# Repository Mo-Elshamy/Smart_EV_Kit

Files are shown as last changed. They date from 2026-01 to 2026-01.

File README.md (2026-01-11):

# Smart EV Kit — Project Overview

The Smart EV Kit combines a Raspberry Pi–based Vehicle Control Unit (VCU) and a set of mechanical parts for an educational electric buggy platform. It integrates secure access (NFC), a touchscreen dashboard, ultrasonic safety sensors, and addressable LED lighting for prototyping and learning.

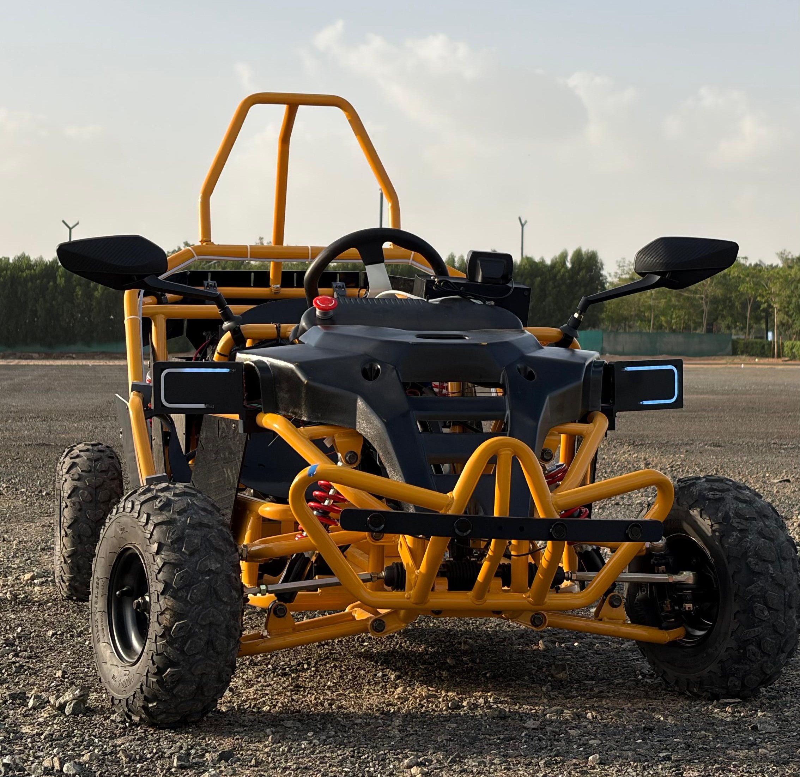
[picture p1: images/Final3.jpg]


---

## [Software & Electrical Hardware](software/Software.md)

Overview: The software stack is written in Python and provides a touch-friendly dashboard, hardware abstraction, and background services for sensors and actuators. Key components include the GUI (`main.py` using PyQt5), the hardware abstraction layer (`hardware.py`) which manages GPIO, SPI (NFC), ultrasonic sensors, LED animations, relays, and the DHT sensor loops.

Electrical hardware summary: Designed for a Raspberry Pi 4 with a 7" HDMI touchscreen, the system uses eight HC-SR04 ultrasonics (echo lines protected by voltage dividers), an RC522 NFC reader on SPI, a WS2811 12V LED strip driven via PWM-capable GPIO, a 2-channel relay module (active-low), and a DHT11 environmental sensor. Power conversion is expected via 48V→12V and 48V→5V buck converters.
Front Bar

---

## [Mechanical](mechanical/Mechacinal.md)

Overview: Mechanical assets include 3D-printed mounts, a multi-part control box, sensor bars, and laser-cut acrylic body panels. The documentation lists fitment issues and recommended V2 improvements (tolerance adjustments, mounting standoffs, and cutout updates) and contains a student steering prototype activity.
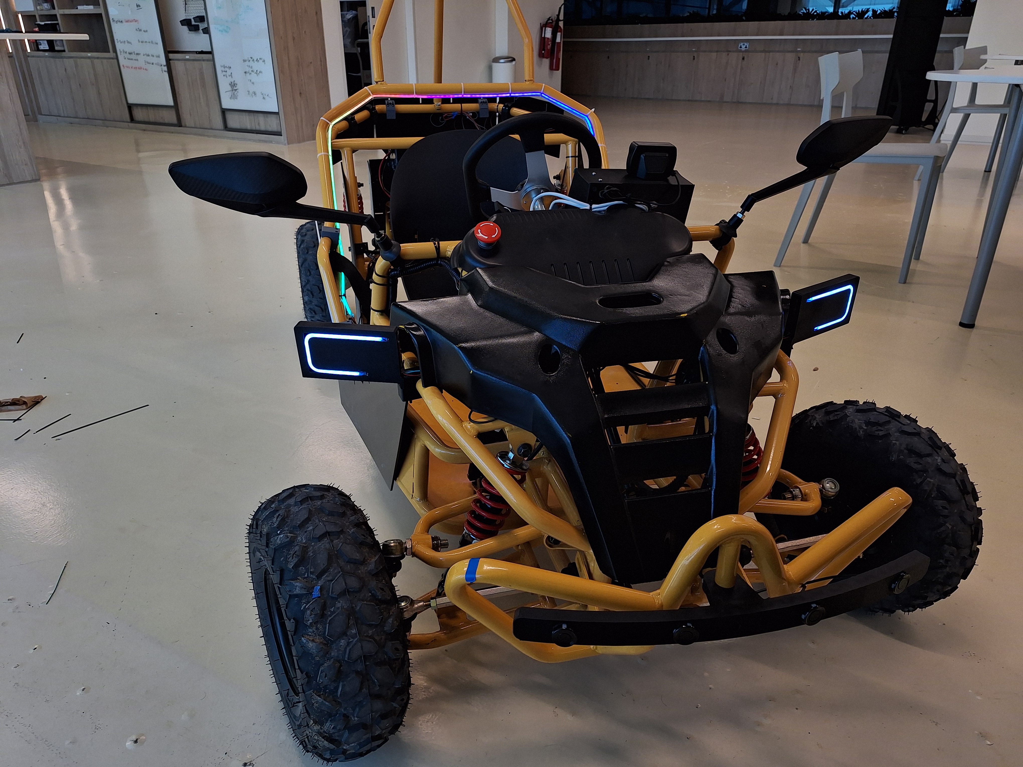
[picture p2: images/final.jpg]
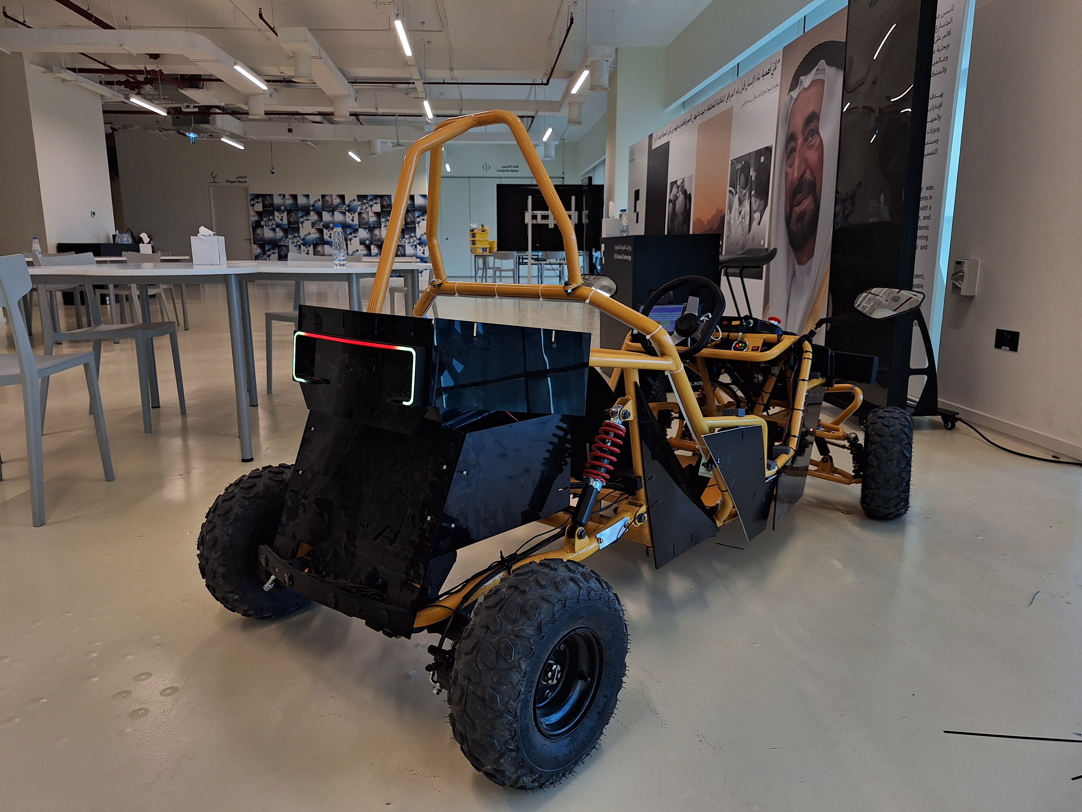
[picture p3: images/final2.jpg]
 |

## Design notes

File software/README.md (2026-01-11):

# RQ EV Car Control System

**Version:** 1.0.0 **Platform:** Raspberry Pi 4 Model B (Bookworm OS)

## 1. Project Overview

The **RQ EV Car Control System** is a centralized Vehicle Control Unit (VCU) designed for electric buggies and educational EV platforms. Built on the Raspberry Pi 4 architecture, it integrates safety sensors, access control, and lighting management into a single, cohesive system.

This project replaces traditional analog car switches with a modern, 7-inch touchscreen interface (`PyQt5`), offering a digital driving experience similar to modern commercial electric vehicles.

### Key Features

* **Keyless Authentication:** Secure NFC/RFID access control prevents the vehicle from starting without an authorized key card.
* **Intelligent Safety System:** An 8-sensor ultrasonic array provides real-time parking assistance with visual radar feedback and variable frequency audio warnings.
* **Dynamic Lighting:** Controls addressable WS2811 LED strips for Headlights, Taillights, Turn Signals, and animated Interior Underglow.
* **Digital Dashboard:** A high-contrast, touch-friendly GUI displays speed (simulated), temperature, humidity, time, and system status.
* **Motor Interlock:** Hardware relays physically isolate the motor control circuits until software authentication is verified.

## 2. Hardware Configuration

### Bill of Materials (BOM)

* **Controller:** Raspberry Pi 4 Model B (4GB or 8GB recommended).
* **Display:** 7-inch HDMI Touchscreen (Waveshare or similar).
* **Power System:**
  * 48V Main Battery Pack.
  * 48V to 12V Buck Converter (for LED Strips).
  * 48V to 5V Buck Converter (for Pi, Sensors, Relays).
* **Sensors:**
  * 8x HC-SR04 Ultrasonic Distance Sensors.
  * 1x RC522 NFC/RFID Reader Module.
  * 1x DHT11 Temperature & Humidity Sensor.
* **Actuators:**
  * WS2811 Addressable LED Strip (12V).
  * 2-Channel 5V Relay Module (Active Low).
  * Active Piezo Buzzer.
* **Circuit Components:**
  * Resistors: 1kΩ and 2kΩ (for 16x Voltage Dividers on Ultrasonic Echo lines).
  * Breadboard or PCB for signal distribution.

### Master Pinout Map (BCM Numbering)

*Note: This configuration corresponds to `hardware.py`.*

| Component | Function | GPIO Pin | Physical Pin | Notes |
| --- | --- | --- | --- | --- |
| **Ultrasonic (x8)** | **TRIG (Shared)** | **GPIO 23** | **16** | One trigger fires all sensors. |
| **Front Sensors** | Echo 1 (Front Left) | **GPIO 17** | 11 | Voltage Divider Required! |
| | Echo 2 (Front Mid-L) | **GPIO 27** | 13 | Voltage Divider Required! |
| | Echo 3 (Front Mid-R) | **GPIO 22** | 15 | Voltage Divider Required! |
| | Echo 4 (Front Right) | **GPIO 5**  | 29 | Voltage Divider Required! |
| **Rear Sensors** | Echo 5 (Rear Left) | **GPIO 6**  | 31 | Voltage Divider Required! |
| | Echo 6 (Rear Mid-L) | **GPIO 24** | 18 | Voltage Divider Required! |
| | Echo 7 (Rear Mid-R) | **GPIO 16** | 36 | Voltage Divider Required! |
| | Echo 8 (Rear Right) | **GPIO 26** | 37 | Voltage Divider Required! |
| **NFC (RC522)** | SDA (Chip Select) | **GPIO 8**  | 24 | SPI Interface (3.3V Only). |
| | SCK (Clock) | **GPIO 11** | 23 | |
| | MOSI | **GPIO 10** | 19 | |
| | MISO | **GPIO 9**  | 21 | |
| | RST (Reset) | **GPIO 19** | 35 | Custom pin assignment. |
| **Lighting** | Data Input | **GPIO 12** | 32 | **PWM0**Channel required for WS2811. |
| **Relays** | Relay 1 (Main Power) | **GPIO 14** | 8 | Active Low Logic. |
| | Relay 2 (Reverse) | **GPIO 15** | 10 | Active Low Logic. |
| **Audio** | Active Buzzer | **GPIO 13** | 33 | |
| **Environment** | DHT11 Data | **GPIO 4**  | 7 | Requires Pull-up resistor. |

## 3. Software Installation

This project runs on  **Raspberry Pi OS (Bookworm)** . Older versions (Bullseye/Buster) may require different GPIO libraries.

### A. System Preparation

1. Update the system:
   ```
   sudo apt update && sudo apt upgrade -y
   ```
2. Enable hardware interfaces:
   * Run `sudo raspi-config`
   * Navigate to  **Interface Options** .
   * Enable **SPI** (for NFC).
   * Enable **SSH** (for remote access).
   * Enable **VNC** (optional, for remote desktop).
3. Reboot the Pi.

### B. Install Dependencies

Install the required system packages and Python libraries. Note the use of `rpi-lgpio` for Bookworm compatibility.

```
# 1. System Libraries
sudo apt install -y python3-rpi-lgpio python3-pip python3-pyqt5 python3-spidev git libgpiod2

# 2. Python Drivers (using break-system-packages is necessary on Bookworm for hardware access)
sudo pip3 install mfrc522 adafruit-circuitpython-dht rpi_ws281x gpiozero --break-system-packages
```

### C. Enable Kiosk Mode (Autostart)

To make the dashboard launch automatically in full screen when the car turns on:

1. Create the autostart directory:
   ```
   mkdir -p ~/.config/autostart
   ```
2. Create a desktop entry file:
   ```
   nano ~/.config/autostart/ev_dashboard.desktop
   ```
3. Paste the following configuration:
   ```
   [Desktop Entry]
   Type=Application
   Name=EV Dashboard
   Exec=sudo -E python3 /home/rqev/EV_Dashboard/main.py
   Terminal=false
   Hidden=false
   X-GNOME-Autostart-enabled=true
   ```
4. **Important:** Configure display permissions for root:
   * Edit `.bashrc`: `nano ~/.bashrc`
   * Add to the bottom: `xhost +local:root`

## 4. Software Architecture & Code Reference

The system is split into two primary distinct layers: the **Hardware Abstraction Layer (HAL)** and the  **User Interface (GUI)** .

### A. Low-Level Control: `hardware.py`

This module acts as the "Body" of the car. It abstracts complex electrical signals (PWM, SPI, GPIO Interrupts) into simple, high-level commands. It runs background threads to ensure critical features (like brake lights or sensor readings) never lag, even if the GUI is busy.

#### Class: `LightingSystem`

Manages the WS2811 Addressable LED strip. It treats the single physical strip as three logical zones.

* **Key Logic:**
  * **Animation Loop:** A background thread (`_animation_loop`) updates the strip every 0.4s to handle blinking turn signals without blocking the main processor.
  * **Zones:**
    * **Front:** Pixels `0` to `LEDS_FRONT_COUNT`. (White, flashes Amber).
    * **Interior:** Middle section. Supports "Solid", "Breathe", and "Rainbow" modes.
    * **Rear:** Last section. (Red, flashes Amber).
* **Function Reference:**
  * `__init__(self)`: Initializes the strip with correct PWM frequency (800kHz) and starts the animation thread.
  * `_animation_loop(self)`: The background worker that calculates blink timing and renders frames to the LEDs.
  * `_render_front(self, blink)`, `_render_interior(self, blink)`, `_render_back(self, blink)`: Internal helpers that draw the specific color logic for each zone.
  * `set_turn_signal(mode)`: Sets signal state. Mode can be 'LEFT', 'RIGHT', 'HAZARD', or 'OFF'.
  * `set_brakes(active)`: Boolean toggle. If True, rear lights brighten.
  * `set_interior_rgb(r, g, b)`: Sets the base color for the interior zone.
  * `set_interior_mode(mode)`: Sets the pattern ('SOLID', 'BREATHE', 'RAINBOW').

#### Class: `CarHardware`

The main controller class that aggregates all sensors and actuators.

* **Sensors:**
  * **Ultrasonic:** Uses `gpiozero.DigitalInputDevice` with callbacks (`_on_echo_rise`, `_on_echo_fall`) to measure pulse width efficiently.
  * **NFC:** Runs in a dedicated thread (`_nfc_loop`) to poll for cards without freezing the app. Checks for hardware presence on boot (Verifies Chip Version).
  * **DHT11:** Runs in a dedicated thread (`_temp_loop`) reading every 2 seconds.
* **Actuators:**
  * **Relays:** Controls Motor (Relay 1) and Reverse (Relay 2) using Active Low logic (Low = ON).
  * **Buzzer:** Non-blocking control via `set_buzzer()`.
* **Function Reference:**
  * `_init_gpio(self)`: Sets up BCM mode, pin directions, and attaches interrupt callbacks for ultrasonic sensors.
  * `_start_threads(self)`: Launches the NFC and Temperature monitoring threads.
  * `trigger_sensors(self)`: Sends a 10µs pulse to the shared Trigger pin to fire all ultrasonic sensors.
  * `set_relay(index, state)`: Controls physical relays (Active Low logic). Index 0 = Main, 1 = Reverse.
  * `set_buzzer(state)`: Turns the active buzzer on or off immediately.
  * `beep(duration)`: Blocking call to beep for a specific duration (use sparingly).
  * `cleanup(self)`: Safely closes threads and resets GPIO pins on exit.

### B. High-Level Interface: `main.py`

This module is the "Brain" of the car. It uses **PyQt5** to render the touchscreen interface and manages the system state (Locked vs. Unlocked).

#### Class: `ParkingVisualizer` (Custom Widget)

A highly optimized graphical widget that draws the car state using `QPainter`.

* **Dynamic Scaling:** Automatically scales the car graphics to fit any screen size while maintaining aspect ratio.
* **Rendering:** Draws a vector-style "Off-Road Buggy" with suspension, chunky tires, and roll cage.
* **Radar:** Visualizes ultrasonic data as color-coded "WiFi-style" arcs (Green/Yellow/Red) around the car.
* **Function Reference:**
  * `update_sensor_data(distances)`: Accepts a list of 8 floats (cm) and triggers a repaint.
  * `paintEvent(event)`: The main drawing loop. Handles coordinate translation, scaling, and drawing the car model.
  * `draw_radar_arc(...)`: Helper to draw the curved signal bars based on distance proximity.
  * `draw_tire(...)`: Helper to draw rotated tires relative to the car body.

#### Class: `EVSystem` (Main Window)

The main application window that manages the screens (`QStackedWidget`).

* **Screens:**
  1. **Locked:** Security screen with PIN pad (Pass: `1234`) and NFC scanning prompt.
  2. **Dashboard:** The driving mode. Displays speed, clock, temp, and controls for Lights, Reverse, and Lock.
  3. **Config:** Settings hub for "Interior Lighting", "Access Control", and "Diagnostics".
  4. **Confirmation:** Safety prompt before locking the vehicle.
* **System Loop (`update_system`):**
  * Runs every  **50ms** .
  * Polls `CarHardware` for new sensor data.
  * Updates the `ParkingVisualizer`.
  * Calculates safety logic: If any object is `< 30cm`, it triggers the high-frequency alarm.
* **Persistence:**
  * Loads/Saves authorized NFC Key IDs to `authorized_keys.txt` so keys are remembered after reboot.
  * Detects the environment (`BASE_DIR`) to ensure assets like `background.png` load correctly on startup.
* **Function Reference:**
  * **Initialization:**
    * `__init__`: Sets up window, hardware link, and starts the heartbeat timer.
    * `apply_background(widget)`: Finds background images and applies them via stylesheet.
  * **Logic:**
    * `update_system()`: The main 50ms loop. Handles NFC checks, sensor triggering, visualizer updates, and beeping logic.
    * `unlock_system(user_id)`: Transitions to Dashboard, turns on Relay 1 (Main Power), and plays welcome animation.
    * `lock_system()`: Transitions to Lock Screen, turns OFF all relays and lights.
  * **Access Control:**
    * `load_authorized_keys()` / `save_authorized_key()`: File I/O for key management.
    * `check_pin()`: Validates the manual PIN entry (Default: "1234").
  * **Configuration:**
    * `update_interior_color()`: Reads RGB sliders and updates the `LightingSystem`.
    * `set_pattern(mode)`: Changes the interior lighting effect mode.
    * `update_diagnostics()`: Populates the diagnostics table with raw sensor data for debugging.

### C. Logic Flow

1. **Boot:** System initializes `hardware.py`. Relays start OFF. NFC reader performs a handshake.
2. **Lock State:** GUI shows Lock Screen. NFC thread waits for a known card ID.
3. **Unlock:** Valid card or PIN -> Relays Energize (Motor ON) -> GUI switches to Dashboard.
4. **Drive:**
   * Ultrasonic sensors update 20 times/second.
   * User toggles "Left Turn" -> `main.py` tells `hardware.py` -> LED Thread blinks specific pixels.
5. **Shutdown/Lock:** User presses Lock -> Relays Cut Power -> System returns to Lock Screen.

## 5. Troubleshooting & Common Issues

This section covers specific errors encountered during development and their solutions.

### A. Display / GUI Errors

**Error:** `qt.qpa.xcb: could not connect to display`

* **Cause:** Trying to run the GUI from an SSH terminal without specifying the display output.
* **Solution:**
  1. Export the display variable: `export DISPLAY=:0`
  2. Grant root permission to screen: `xhost +local:root`
  3. Run with environment preservation: `sudo -E python3 main.py`

### B. NFC Reader Issues

**Error:** `0xb2` or `Warning: Reader returned strange version`

* **Cause:** Data corruption on the MISO line (Bit flipping). Usually caused by loose wiring or "Safe Mode" speed required.
* **Solution:**
  1. Check connections on **GPIO 9 (MISO)** and  **GPIO 11 (SCK)** .
  2. Ensure the reader is powered by **3.3V** (NOT 5V).
  3. The software includes a "Handshake" check on startup. If it fails, check physical soldering on the blue module headers.

### C. Ultrasonic Sensors

**Error:** `RuntimeError: Failed to add edge detection`

* **Cause:** Conflict between the old `RPi.GPIO` library and the new Raspberry Pi OS (Bookworm) kernel.
* **Solution:** The project uses `gpiozero` and `rpi-lgpio` internally to bypass this. Do not uninstall these libraries.

**Issue:** Readings are always 0.0cm.

* **Cause:** Voltage divider resistors (1kΩ/2kΩ) might be loose, or the sensor is not powered with 5V.
* **Check:** Ensure the **VCC** of the sensor goes to  **5V** , but the **Echo** goes through the resistors before hitting the Pi's **3.3V** pin.

### D. LED Issues

**Issue:** LEDs colors are swapped (e.g., Red is Green).

* **Solution:** The strip type is set in `hardware.py`.
  * Current setting: `ws.WS2811_STRIP_RGB`
  * If you change strips, edit the `PixelStrip` initialization line to `STRIP_GRB` or `STRIP_BRG`.

**Issue:** LEDs flicker randomly.

* **Cause:** Missing Common Ground.
* **Solution:** Ensure the **Black Wire** (GND) from the 12V Buck Converter connects to **BOTH** the LED Strip and the Raspberry Pi Pin 6/9/14.

### E. Relays

**Issue:** Relays start ON when the system boots.

* **Cause:** Most relay modules are "Active Low" (Low signal = ON).
* **Solution:** The code initializes pins to `GPIO.HIGH` (OFF) on boot to prevent this. If you change relay modules, check if they are Active High or Low.

## 6. How to Edit

To adjust settings without rewriting code, edit the top section of `hardware.py`:

```
# ==========================================
#   USER CONFIGURATION
# ==========================================
LEDS_FRONT_COUNT    = 6   # Change LED counts here
LEDS_INTERIOR_COUNT = 24
LEDS_BACK_COUNT     = 8

PIN_LED_DATA = 12         # Change GPIO pins here

```

## 7. Notes and Future Adjustments

This section documents critical bugs fixed during initial development to prevent regression in future updates.

### Resolved Critical Bugs

1. **Light Control Failure:**
   * **Problem:** The GUI buttons for lights and interior patterns were unresponsive, and the lights remained stuck in the "ON" state.
   * **Fix:** The `hardware.py` logic was updated to correctly map GUI toggle signals to the LED animation loop.
2. **Unintended Motion (Safety Critical):**
   * **Problem:** Upon system boot or unlock, the Motor Relay (Relay 1) would energize immediately, potentially causing the car to move before the software was ready.
   * **Fix:** The relay logic was inverted (Active Low) and the initialization state was explicitly set to `GPIO.HIGH` (OFF) to ensure the car remains stationary until the user explicitly engages it.

**Project Completed.**

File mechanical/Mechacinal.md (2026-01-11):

# Mechanical Design & Prototyping

This directory contains all mechanical assets for the EV project, including 3D printable STL files, 2D laser-cutting profiles for the acrylic body, and archived resources for student activities.

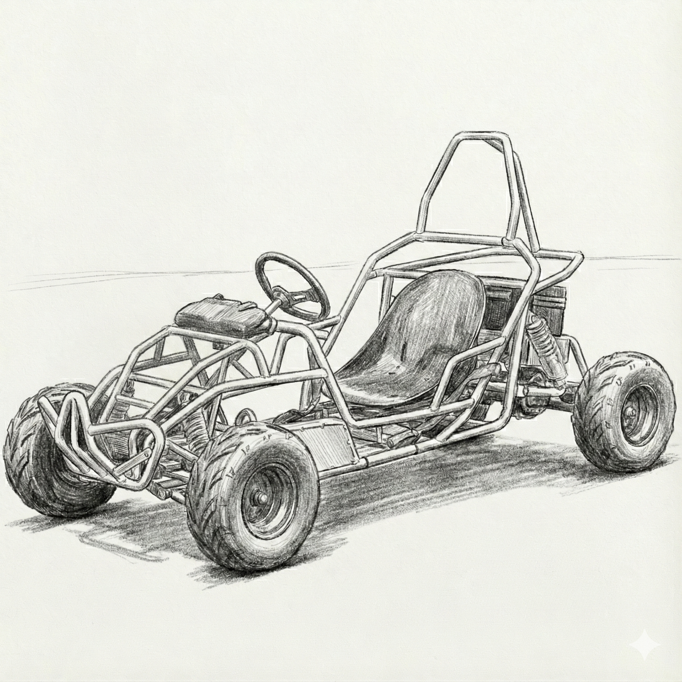
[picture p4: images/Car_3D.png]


## 📂 Directory Structure

```
mechanical/
├── 3D_Printed_Parts/          # Custom parts for sensors, control units, and mounts
├── Acrylic_Covers/            # 2D profiles for body panels (laser cut)
├── Steering_Prototype.zip     # Archived prototype files for student steering activity
└── README.md                  # This documentation file

```

## 1. [3D Printed Parts](mechanical/3D_Printed_Parts/)
*Material Recommendation: PLA*

| Component | Preview | Function / Description | ⚠️ Design Defects & V2 Improvements |
| --- | --- | --- | --- |
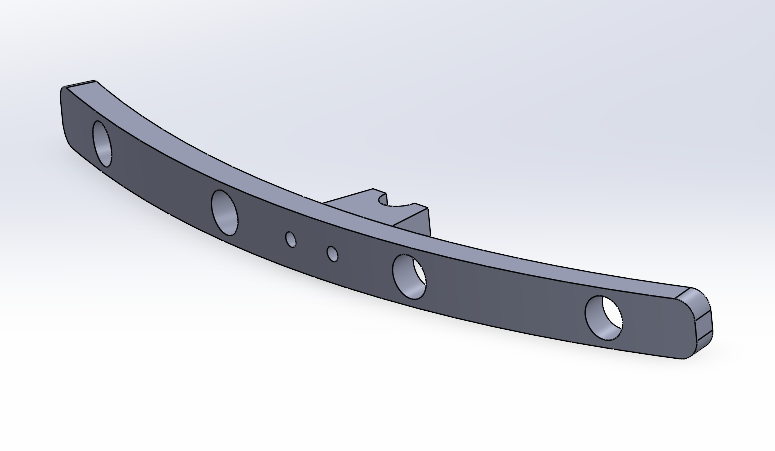
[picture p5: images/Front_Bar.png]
Front Bar
| **Front Bar** |  | Mounts the waterproof ultrasonic sensors to the front chassis. | **Tolerance Issue:** Sensor holes are too tight. →*Fix:* Increase hole diameter for proper fit. |
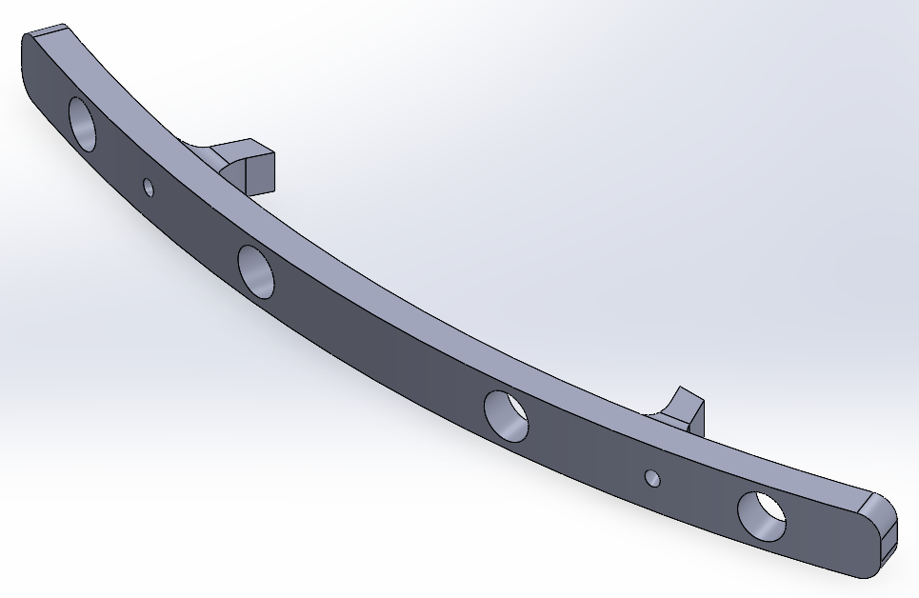
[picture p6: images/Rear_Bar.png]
Rear Bar
| **Back Bar** |  | Mounts rear ultrasonic sensors. Interfaces with the*Holder*piece. | **Alignment Issue:** Screw holes are tilted, causing misalignment with the holder. Sensor holes are also too tight. →*Fix:* Straighten screw channels and increase sensor hole size. |
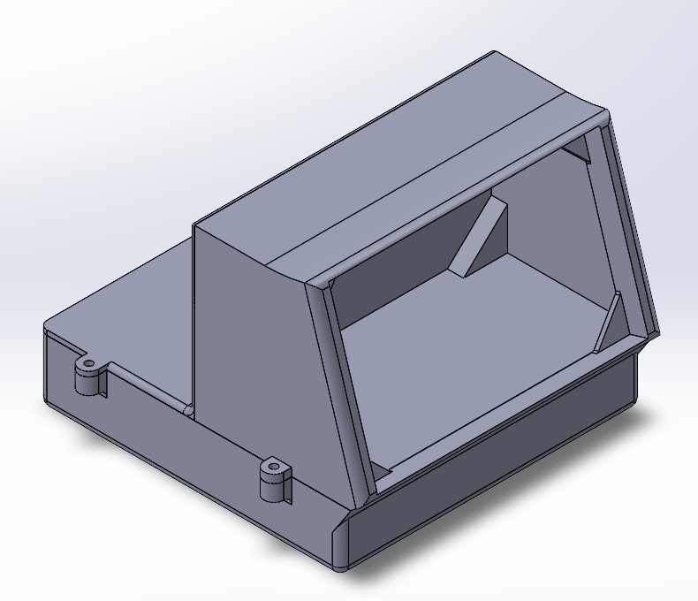
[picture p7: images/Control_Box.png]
Control Box
| **Control Box** |  | 3-part main control unit housing. Holds the Touch Screen, Raspberry Pi, Sensors, and Relays. | **Volume & Fitment Issues:** 1. Bottom face is closed, restricting inner space.*Fix: Open the ground face.* 2. Screen mounting is improper, causing bending when screws are tightened.*Fix: Add dedicated screen mounting holes/standoffs.* |
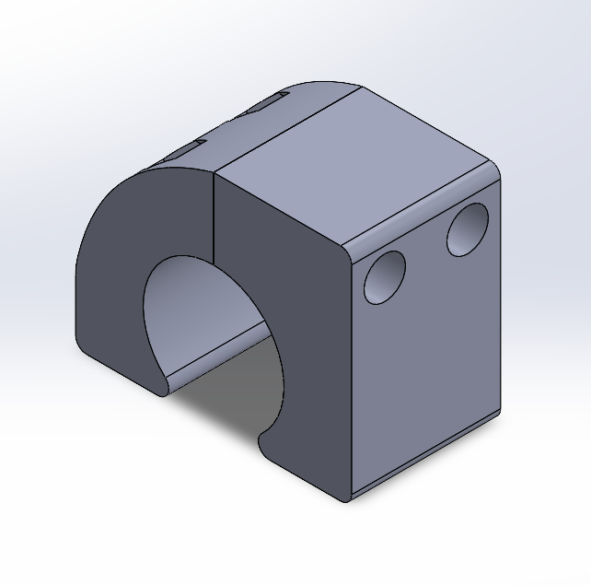
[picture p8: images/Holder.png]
Chassis Holder
| **Chassis Holder**  |  | 2-piece clamp mechanism that locks onto the tubular chassis. Anchors the acrylic sheets and sensor bars. | **Fitment Issue:** Inner diameter is too large to grip the tube securely. →*Fix:* Reduce inner diameter to ensure a tight friction fit when screwed down. |
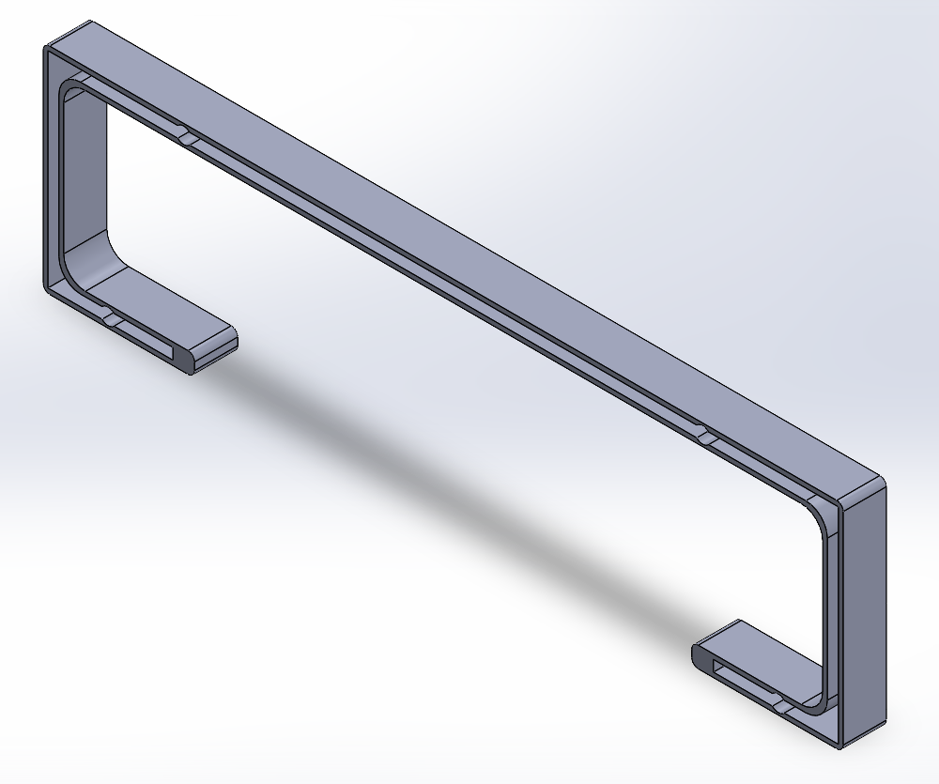
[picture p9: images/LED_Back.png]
Back LED
| **Back LED** |  | Grooved bar mounted on the*Back Cover* . Holds the neon LED strip. | ✅**Ready:** No reported issues. |
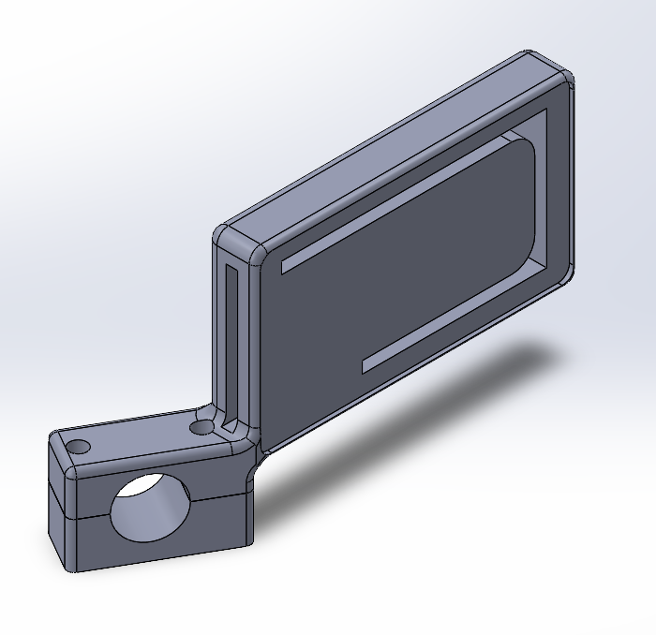
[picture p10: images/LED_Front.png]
Front LED (L/R)
| **Front LED (L/R)** |  | "Side Mirror" style housings (Left & Right) with grooves for neon LED strips. | **Angle Issue:** The mount angle causes lights to point incorrectly. →*Fix:*Adjust mounting angle to face straight forward. |

## 2. [Acrylic Body Covers](/Smart_EV_Kit/mechanical/Acrylic_Covers/)

*Material Recommendation: 3mm or 4mm Acrylic / Polycarbonate.*

| Assembly Group | Function / Description | ⚠️ Design Defects & V2 Improvements |
| --- | --- | --- |
| **Back Cover (Lower)** | 3-part assembly covering the motor/battery area. Includes cutouts for the**Circuit Breaker**and **Charging Port** . | ✅**Ready:** Accessibility features work well (charging possible without removal). |
| **Back Cover (Upper)** | 5-part assembly for the upper-rear roll cage. The middle section supports the*Back LED*bar. | ✅**Ready:** Fits correctly. |
| **Front Cover** | 3-part assembly intended for the nose/hood. | ❌**Failed:** Multiple chassis angles made fitment impossible. →*Action:* Reverted to original stock cover (repainted). |
| **Side Cover** | 3-part assembly protecting the vehicle sides. | **Fitment Issue:** Missing cutout for the driver's seatbelt anchor. →*Fix:* Add relief cut to accommodate the seatbelt bolt. |

## 3. Student Activity Resources

### 📦 [Steering_Prototype](/Smart_EV_Kit/mechanical/rack-and-pinion-steering-model_Activity.zip)

Front Bar

**Description:** A compressed archive containing prototype files and assets for the student steering mechanism activity.

**Contents:**

* CAD Files for steering linkage prototype.
* Reference documentation for student assembly.

*Last Updated: January 2026*

## [Back To Main]()

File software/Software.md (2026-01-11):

# RQ EV Car Control System

**Version:** 1.0.0 **Platform:** Raspberry Pi 4 Model B (Bookworm OS)

## 1. Project Overview

The **RQ EV Car Control System** is a centralized Vehicle Control Unit (VCU) designed for electric buggies and educational EV platforms. Built on the Raspberry Pi 4 architecture, it integrates safety sensors, access control, and lighting management into a single, cohesive system.

This project replaces traditional analog car switches with a modern, 7-inch touchscreen interface (`PyQt5`), offering a digital driving experience similar to modern commercial electric vehicles.

### Key Features

* **Keyless Authentication:** Secure NFC/RFID access control prevents the vehicle from starting without an authorized key card.
* **Intelligent Safety System:** An 8-sensor ultrasonic array provides real-time parking assistance with visual radar feedback and variable frequency audio warnings.
* **Dynamic Lighting:** Controls addressable WS2811 LED strips for Headlights, Taillights, Turn Signals, and animated Interior Underglow.
* **Digital Dashboard:** A high-contrast, touch-friendly GUI displays speed (simulated), temperature, humidity, time, and system status.
* **Motor Interlock:** Hardware relays physically isolate the motor control circuits until software authentication is verified.
Front Bar

## 2. Hardware Configuration

### Bill of Materials (BOM)

* **Controller:** Raspberry Pi 4 Model B (4GB or 8GB recommended).
* **Display:** 7-inch HDMI Touchscreen (Waveshare or similar).
* **Power System:**
  * 48V Main Battery Pack.
  * 48V to 12V Buck Converter (for LED Strips).
  * 48V to 5V Buck Converter (for Pi, Sensors, Relays).
* **Sensors:**
  * 8x HC-SR04 Ultrasonic Distance Sensors.
  * 1x RC522 NFC/RFID Reader Module.
  * 1x DHT11 Temperature & Humidity Sensor.
* **Actuators:**
  * WS2811 Addressable LED Strip (12V).
  * 2-Channel 5V Relay Module (Active Low).
  * Active Piezo Buzzer.
* **Circuit Components:**
  * Resistors: 1kΩ and 2kΩ (for 16x Voltage Dividers on Ultrasonic Echo lines).
  * Breadboard or PCB for signal distribution.

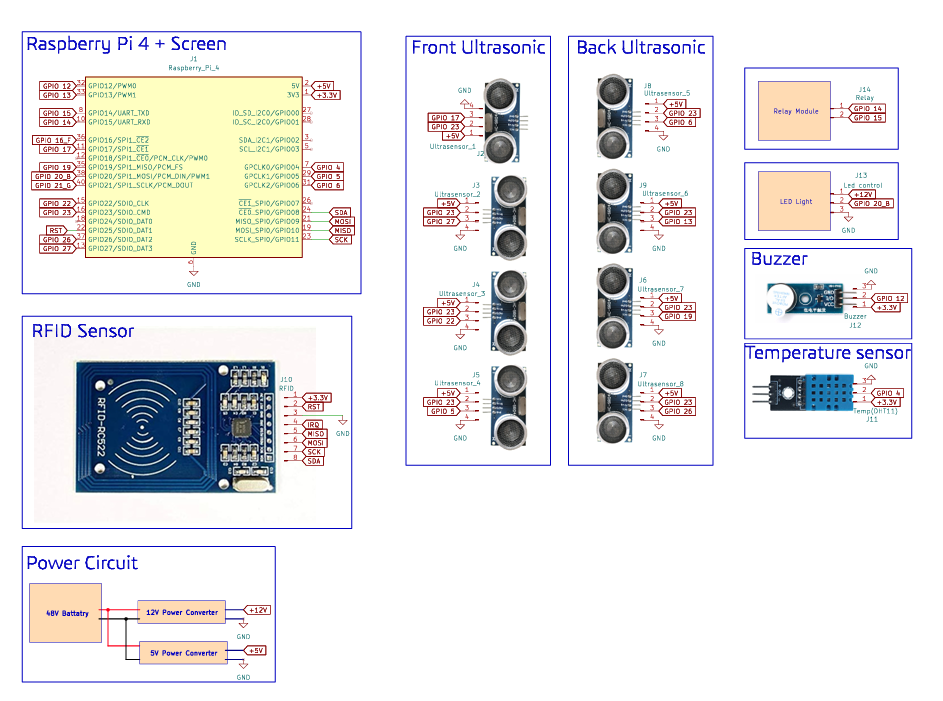
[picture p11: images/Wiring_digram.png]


### Master Pinout Map (BCM Numbering)

*Note: This configuration corresponds to `hardware.py`.*

| Component | Function | GPIO Pin | Physical Pin | Notes |
| --- | --- | --- | --- | --- |
| **Ultrasonic (x8)** | **TRIG (Shared)** | **GPIO 23** | **16** | One trigger fires all sensors. |
| **Front Sensors** | Echo 1 (Front Left) | **GPIO 17** | 11 | Voltage Divider Required! |
| | Echo 2 (Front Mid-L) | **GPIO 27** | 13 | Voltage Divider Required! |
| | Echo 3 (Front Mid-R) | **GPIO 22** | 15 | Voltage Divider Required! |
| | Echo 4 (Front Right) | **GPIO 5**  | 29 | Voltage Divider Required! |
| **Rear Sensors** | Echo 5 (Rear Left) | **GPIO 6**  | 31 | Voltage Divider Required! |
| | Echo 6 (Rear Mid-L) | **GPIO 24** | 18 | Voltage Divider Required! |
| | Echo 7 (Rear Mid-R) | **GPIO 16** | 36 | Voltage Divider Required! |
| | Echo 8 (Rear Right) | **GPIO 26** | 37 | Voltage Divider Required! |
| **NFC (RC522)** | SDA (Chip Select) | **GPIO 8**  | 24 | SPI Interface (3.3V Only). |
| | SCK (Clock) | **GPIO 11** | 23 | |
| | MOSI | **GPIO 10** | 19 | |
| | MISO | **GPIO 9**  | 21 | |
| | RST (Reset) | **GPIO 19** | 35 | Custom pin assignment. |
| **Lighting** | Data Input | **GPIO 12** | 32 | **PWM0**Channel required for WS2811. |
| **Relays** | Relay 1 (Main Power) | **GPIO 14** | 8 | Active Low Logic. |
| | Relay 2 (Reverse) | **GPIO 15** | 10 | Active Low Logic. |
| **Audio** | Active Buzzer | **GPIO 13** | 33 | |
| **Environment** | DHT11 Data | **GPIO 4**  | 7 | Requires Pull-up resistor. |

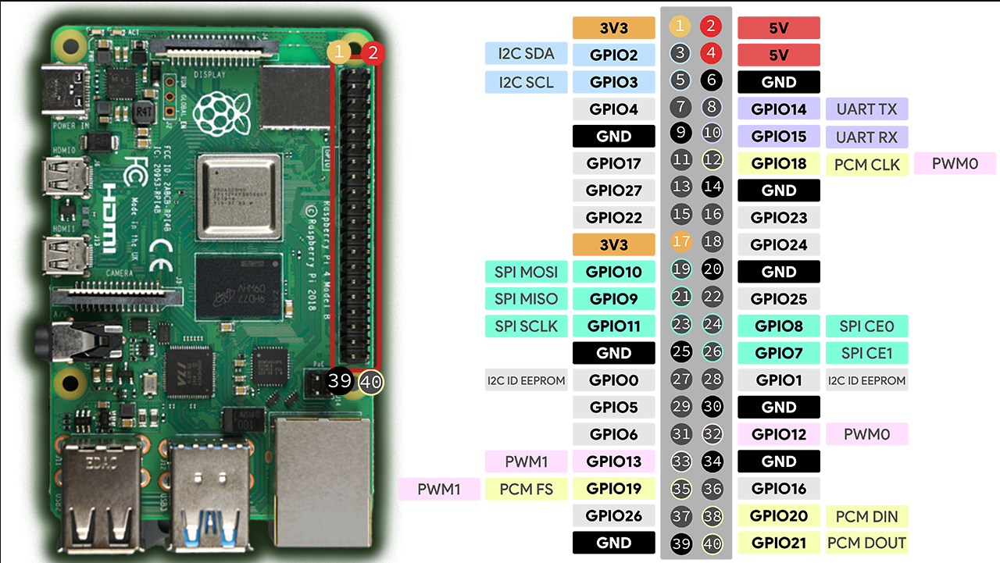
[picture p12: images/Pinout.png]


## 3. Software Installation

This project runs on  **Raspberry Pi OS (Bookworm)** . Older versions (Bullseye/Buster) may require different GPIO libraries.

### A. System Preparation

1. Update the system:
   ```
   sudo apt update && sudo apt upgrade -y
   ```
2. Enable hardware interfaces:
   * Run `sudo raspi-config`
   * Navigate to  **Interface Options** .
   * Enable **SPI** (for NFC).
   * Enable **SSH** (for remote access).
   * Enable **VNC** (optional, for remote desktop).
3. Reboot the Pi.

### B. Install Dependencies

Install the required system packages and Python libraries. Note the use of `rpi-lgpio` for Bookworm compatibility.

```
# 1. System Libraries
sudo apt install -y python3-rpi-lgpio python3-pip python3-pyqt5 python3-spidev git libgpiod2

# 2. Python Drivers (using break-system-packages is necessary on Bookworm for hardware access)
sudo pip3 install mfrc522 adafruit-circuitpython-dht rpi_ws281x gpiozero --break-system-packages
```

### C. Enable Kiosk Mode (Autostart)

To make the dashboard launch automatically in full screen when the car turns on:

1. Create the autostart directory:
   ```
   mkdir -p ~/.config/autostart
   ```
2. Create a desktop entry file:
   ```
   nano ~/.config/autostart/ev_dashboard.desktop
   ```
3. Paste the following configuration:
   ```
   [Desktop Entry]
   Type=Application
   Name=EV Dashboard
   Exec=sudo -E python3 /home/rqev/EV_Dashboard/main.py
   Terminal=false
   Hidden=false
   X-GNOME-Autostart-enabled=true
   ```
4. **Important:** Configure display permissions for root:
   * Edit `.bashrc`: `nano ~/.bashrc`
   * Add to the bottom: `xhost +local:root`

## 4. Software Architecture & Code Reference

The system is split into two primary distinct layers: the **Hardware Abstraction Layer (HAL)** and the  **User Interface (GUI)** .

### A. Low-Level Control: `hardware.py`

This module acts as the "Body" of the car. It abstracts complex electrical signals (PWM, SPI, GPIO Interrupts) into simple, high-level commands. It runs background threads to ensure critical features (like brake lights or sensor readings) never lag, even if the GUI is busy.

#### Class: `LightingSystem`

Manages the WS2811 Addressable LED strip. It treats the single physical strip as three logical zones.

* **Key Logic:**
  * **Animation Loop:** A background thread (`_animation_loop`) updates the strip every 0.4s to handle blinking turn signals without blocking the main processor.
  * **Zones:**
    * **Front:** Pixels `0` to `LEDS_FRONT_COUNT`. (White, flashes Amber).
    * **Interior:** Middle section. Supports "Solid", "Breathe", and "Rainbow" modes.
    * **Rear:** Last section. (Red, flashes Amber).
* **Function Reference:**
  * `__init__(self)`: Initializes the strip with correct PWM frequency (800kHz) and starts the animation thread.
  * `_animation_loop(self)`: The background worker that calculates blink timing and renders frames to the LEDs.
  * `_render_front(self, blink)`, `_render_interior(self, blink)`, `_render_back(self, blink)`: Internal helpers that draw the specific color logic for each zone.
  * `set_turn_signal(mode)`: Sets signal state. Mode can be 'LEFT', 'RIGHT', 'HAZARD', or 'OFF'.
  * `set_brakes(active)`: Boolean toggle. If True, rear lights brighten.
  * `set_interior_rgb(r, g, b)`: Sets the base color for the interior zone.
  * `set_interior_mode(mode)`: Sets the pattern ('SOLID', 'BREATHE', 'RAINBOW').

#### Class: `CarHardware`

The main controller class that aggregates all sensors and actuators.

* **Sensors:**
  * **Ultrasonic:** Uses `gpiozero.DigitalInputDevice` with callbacks (`_on_echo_rise`, `_on_echo_fall`) to measure pulse width efficiently.
  * **NFC:** Runs in a dedicated thread (`_nfc_loop`) to poll for cards without freezing the app. Checks for hardware presence on boot (Verifies Chip Version).
  * **DHT11:** Runs in a dedicated thread (`_temp_loop`) reading every 2 seconds.
* **Actuators:**
  * **Relays:** Controls Motor (Relay 1) and Reverse (Relay 2) using Active Low logic (Low = ON).
  * **Buzzer:** Non-blocking control via `set_buzzer()`.
* **Function Reference:**
  * `_init_gpio(self)`: Sets up BCM mode, pin directions, and attaches interrupt callbacks for ultrasonic sensors.
  * `_start_threads(self)`: Launches the NFC and Temperature monitoring threads.
  * `trigger_sensors(self)`: Sends a 10µs pulse to the shared Trigger pin to fire all ultrasonic sensors.
  * `set_relay(index, state)`: Controls physical relays (Active Low logic). Index 0 = Main, 1 = Reverse.
  * `set_buzzer(state)`: Turns the active buzzer on or off immediately.
  * `beep(duration)`: Blocking call to beep for a specific duration (use sparingly).
  * `cleanup(self)`: Safely closes threads and resets GPIO pins on exit.

### B. High-Level Interface: `main.py`

This module is the "Brain" of the car. It uses **PyQt5** to render the touchscreen interface and manages the system state (Locked vs. Unlocked).

#### Class: `ParkingVisualizer` (Custom Widget)

A highly optimized graphical widget that draws the car state using `QPainter`.

* **Dynamic Scaling:** Automatically scales the car graphics to fit any screen size while maintaining aspect ratio.
* **Rendering:** Draws a vector-style "Off-Road Buggy" with suspension, chunky tires, and roll cage.
* **Radar:** Visualizes ultrasonic data as color-coded "WiFi-style" arcs (Green/Yellow/Red) around the car.
* **Function Reference:**
  * `update_sensor_data(distances)`: Accepts a list of 8 floats (cm) and triggers a repaint.
  * `paintEvent(event)`: The main drawing loop. Handles coordinate translation, scaling, and drawing the car model.
  * `draw_radar_arc(...)`: Helper to draw the curved signal bars based on distance proximity.
  * `draw_tire(...)`: Helper to draw rotated tires relative to the car body.

#### Class: `EVSystem` (Main Window)

The main application window that manages the screens (`QStackedWidget`).

* **Screens:**
  1. **Locked:** Security screen with PIN pad (Pass: `1234`) and NFC scanning prompt.
  2. **Dashboard:** The driving mode. Displays speed, clock, temp, and controls for Lights, Reverse, and Lock.
  3. **Config:** Settings hub for "Interior Lighting", "Access Control", and "Diagnostics".
  4. **Confirmation:** Safety prompt before locking the vehicle.
* **System Loop (`update_system`):**
  * Runs every  **50ms** .
  * Polls `CarHardware` for new sensor data.
  * Updates the `ParkingVisualizer`.
  * Calculates safety logic: If any object is `< 30cm`, it triggers the high-frequency alarm.
* **Persistence:**
  * Loads/Saves authorized NFC Key IDs to `authorized_keys.txt` so keys are remembered after reboot.
  * Detects the environment (`BASE_DIR`) to ensure assets like `background.png` load correctly on startup.
* **Function Reference:**
  * **Initialization:**
    * `__init__`: Sets up window, hardware link, and starts the heartbeat timer.
    * `apply_background(widget)`: Finds background images and applies them via stylesheet.
  * **Logic:**
    * `update_system()`: The main 50ms loop. Handles NFC checks, sensor triggering, visualizer updates, and beeping logic.
    * `unlock_system(user_id)`: Transitions to Dashboard, turns on Relay 1 (Main Power), and plays welcome animation.
    * `lock_system()`: Transitions to Lock Screen, turns OFF all relays and lights.
  * **Access Control:**
    * `load_authorized_keys()` / `save_authorized_key()`: File I/O for key management.
    * `check_pin()`: Validates the manual PIN entry (Default: "1234").
  * **Configuration:**
    * `update_interior_color()`: Reads RGB sliders and updates the `LightingSystem`.
    * `set_pattern(mode)`: Changes the interior lighting effect mode.
    * `update_diagnostics()`: Populates the diagnostics table with raw sensor data for debugging.

### C. Logic Flow

1. **Boot:** System initializes `hardware.py`. Relays start OFF. NFC reader performs a handshake.
2. **Lock State:** GUI shows Lock Screen. NFC thread waits for a known card ID.
3. **Unlock:** Valid card or PIN -> Relays Energize (Motor ON) -> GUI switches to Dashboard.
4. **Drive:**
   * Ultrasonic sensors update 20 times/second.
   * User toggles "Left Turn" -> `main.py` tells `hardware.py` -> LED Thread blinks specific pixels.
5. **Shutdown/Lock:** User presses Lock -> Relays Cut Power -> System returns to Lock Screen.

## 5. Troubleshooting & Common Issues

This section covers specific errors encountered during development and their solutions.

### A. Display / GUI Errors

**Error:** `qt.qpa.xcb: could not connect to display`

* **Cause:** Trying to run the GUI from an SSH terminal without specifying the display output.
* **Solution:**
  1. Export the display variable: `export DISPLAY=:0`
  2. Grant root permission to screen: `xhost +local:root`
  3. Run with environment preservation: `sudo -E python3 main.py`

### B. NFC Reader Issues

**Error:** `0xb2` or `Warning: Reader returned strange version`

* **Cause:** Data corruption on the MISO line (Bit flipping). Usually caused by loose wiring or "Safe Mode" speed required.
* **Solution:**
  1. Check connections on **GPIO 9 (MISO)** and  **GPIO 11 (SCK)** .
  2. Ensure the reader is powered by **3.3V** (NOT 5V).
  3. The software includes a "Handshake" check on startup. If it fails, check physical soldering on the blue module headers.

### C. Ultrasonic Sensors

**Error:** `RuntimeError: Failed to add edge detection`

* **Cause:** Conflict between the old `RPi.GPIO` library and the new Raspberry Pi OS (Bookworm) kernel.
* **Solution:** The project uses `gpiozero` and `rpi-lgpio` internally to bypass this. Do not uninstall these libraries.

**Issue:** Readings are always 0.0cm.

* **Cause:** Voltage divider resistors (1kΩ/2kΩ) might be loose, or the sensor is not powered with 5V.
* **Check:** Ensure the **VCC** of the sensor goes to  **5V** , but the **Echo** goes through the resistors before hitting the Pi's **3.3V** pin.

### D. LED Issues

**Issue:** LEDs colors are swapped (e.g., Red is Green).

* **Solution:** The strip type is set in `hardware.py`.
  * Current setting: `ws.WS2811_STRIP_RGB`
  * If you change strips, edit the `PixelStrip` initialization line to `STRIP_GRB` or `STRIP_BRG`.

**Issue:** LEDs flicker randomly.

* **Cause:** Missing Common Ground.
* **Solution:** Ensure the **Black Wire** (GND) from the 12V Buck Converter connects to **BOTH** the LED Strip and the Raspberry Pi Pin 6/9/14.

### E. Relays

**Issue:** Relays start ON when the system boots.

* **Cause:** Most relay modules are "Active Low" (Low signal = ON).
* **Solution:** The code initializes pins to `GPIO.HIGH` (OFF) on boot to prevent this. If you change relay modules, check if they are Active High or Low.

## 6. How to Edit

To adjust settings without rewriting code, edit the top section of `hardware.py`:

```
# ==========================================
#   USER CONFIGURATION
# ==========================================
LEDS_FRONT_COUNT    = 6   # Change LED counts here
LEDS_INTERIOR_COUNT = 24
LEDS_BACK_COUNT     = 8

PIN_LED_DATA = 12         # Change GPIO pins here

```

## 7. Notes and Future Adjustments

This section documents critical bugs fixed during initial development to prevent regression in future updates.

### Resolved Critical Bugs

1. **Light Control Failure:**
   * **Problem:** The GUI buttons for lights and interior patterns were unresponsive, and the lights remained stuck in the "ON" state.
   * **Fix:** The `hardware.py` logic was updated to correctly map GUI toggle signals to the LED animation loop.
2. **Unintended Motion (Safety Critical):**
   * **Problem:** Upon system boot or unlock, the Motor Relay (Relay 1) would energize immediately, potentially causing the car to move before the software was ready.
   * **Fix:** The relay logic was inverted (Active Low) and the initialization state was explicitly set to `GPIO.HIGH` (OFF) to ensure the car remains stationary until the user explicitly engages it.

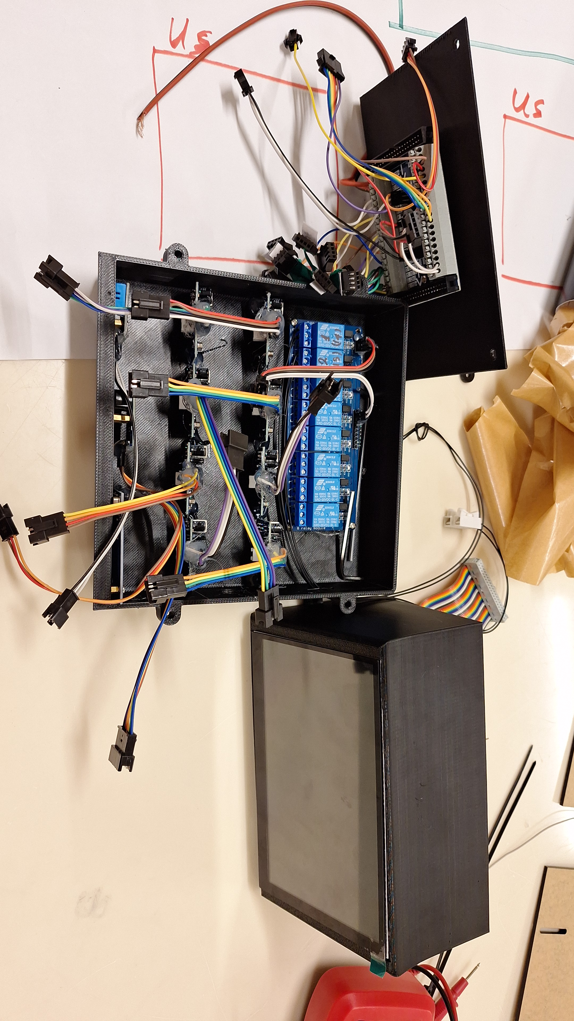
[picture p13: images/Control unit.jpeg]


## [Back To Main](/Smart_EV_Kit/README.md)

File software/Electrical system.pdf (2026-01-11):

### 1. Power Architecture

The system utilizes a multi-voltage architecture derived from a main 48V traction battery. All subsystems share a Common Ground (GND) reference to ensure signal integrity between highvoltage LEDs and low-voltage logic.

- Source: 48V DC Battery.
- 12V Rail (via Buck Converter): Powers the WS2811 Addressable LED Strips (Headlights, Taillights, Underglow).
- 5V Rail (via Buck Converter): Powers the Raspberry Pi 4, 8x Ultrasonic Sensors, and Relay Module.
- 3.3V Rail (via Raspberry Pi): Powers sensitive logic modules (NFC Reader, DHT11, Buzzer).

### 2. Input Subsystems (Sensors)

- Parking Assist (Ultrasonic Array):
- Hardware: 8x HC-SR04 Sensors (4 Front, 4 Rear).
- Logic: Uses a Shared Trigger configuration (One GPIO triggers all sensors simultaneously) to save pins.
- Safety Circuit: Each "Echo" pin utilizes a Voltage Divider (1kΩ + 2kΩ) to step down the 5V return signal to a safe 3.3V for the Raspberry Pi.
- Access Control:
- Hardware: RC522 NFC/RFID Reader.
- Interface: SPI (Serial Peripheral Interface).
- Function: Authenticates user key cards to unlock the motor relays and dashboard.
- Climate Monitoring:
- Hardware: DHT11 Sensor.
- Function: Digital Temperature and Humidity reading.

### 3. Output Subsystems (Actuators)

- Smart Lighting:
- Hardware: WS2811 Addressable LED Strip (12V).
- Topology: Single data line (GPIO 18) daisy-chained to control Front, Interior, and Rear zones independently via software.
- Motor Control:
- Hardware: 2-Channel 5V Relay Module.
- Function: Physically cuts or enables the ignition/motor circuit based on NFC authentication.
- Audio Warning:
- Hardware: Active Piezo Buzzer.
- Function: Provides acoustic feedback for parking proximity and system alerts.

### 4. Software Architecture

- OS: Raspberry Pi OS (Bookworm/Debian 12).
- Interface: Python 3 + PyQt5 (Touchscreen GUI).
- Back-End:
- hardware.py: Handles GPIO interrupts, threading for NFC/Sensors, and LED signal generation (rpi_ws281x).
- main.py: Manages the GUI, State Machine (Locked/Unlocked), and visualizes sensor data.

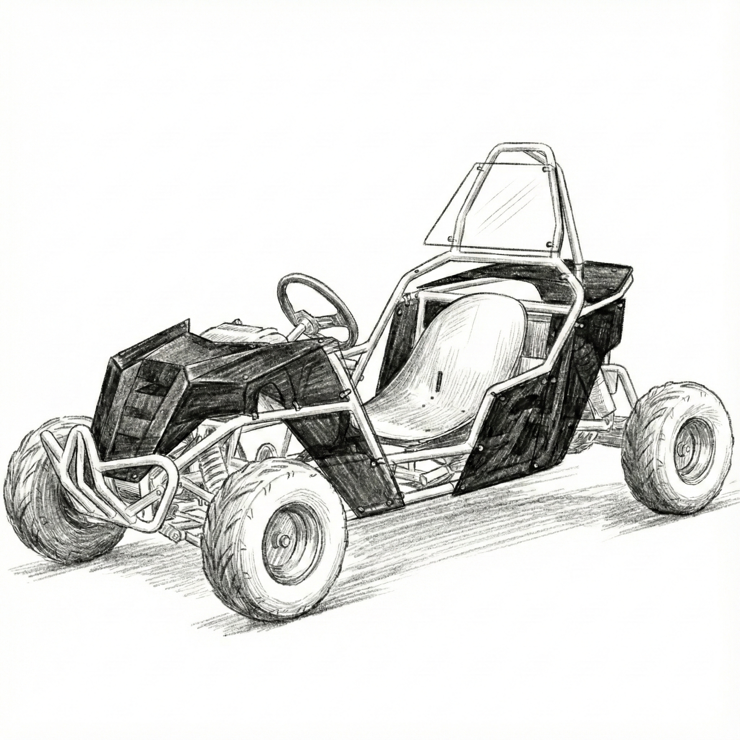
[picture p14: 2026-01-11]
images/Car_3D_Concept.png

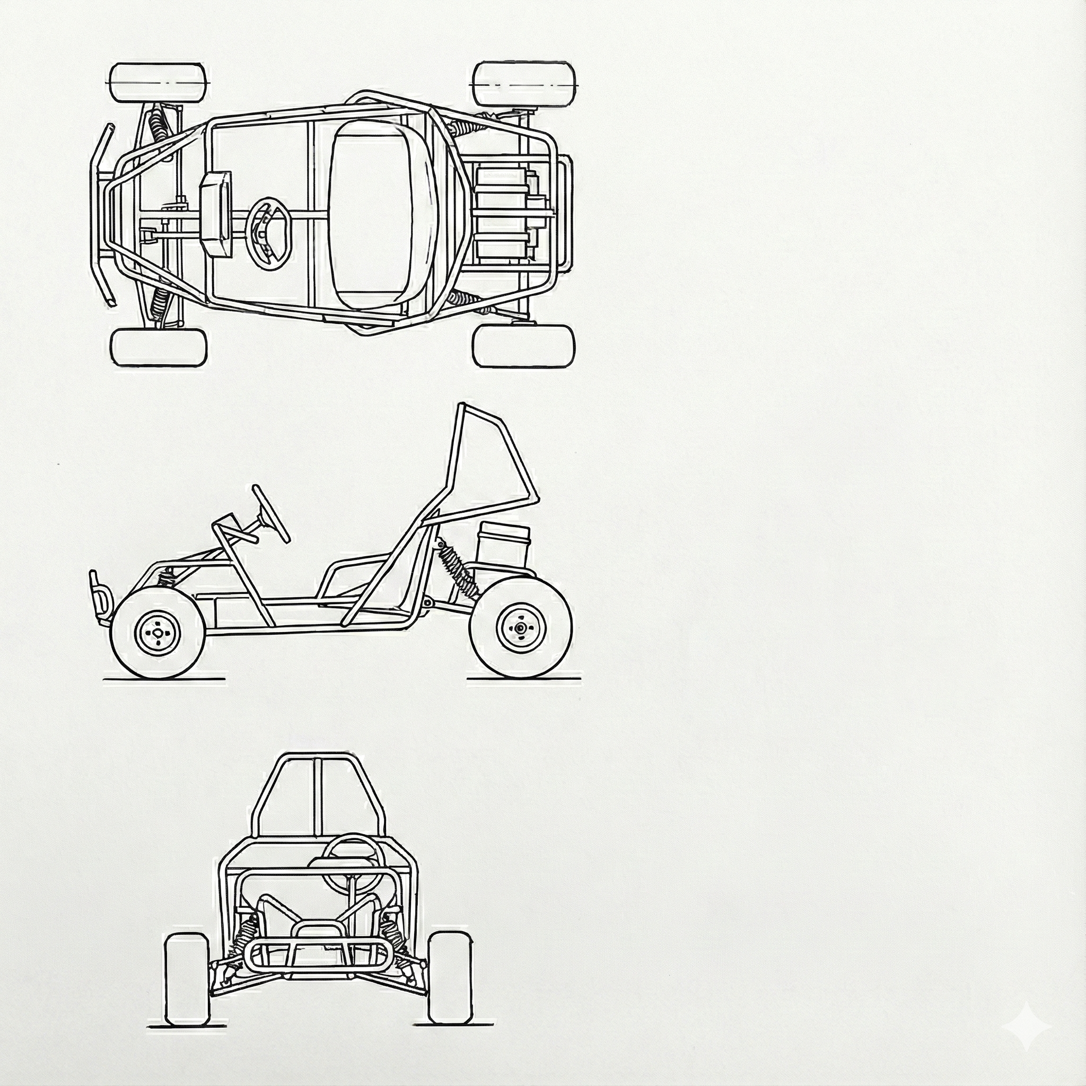
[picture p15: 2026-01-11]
images/Car_2d.png

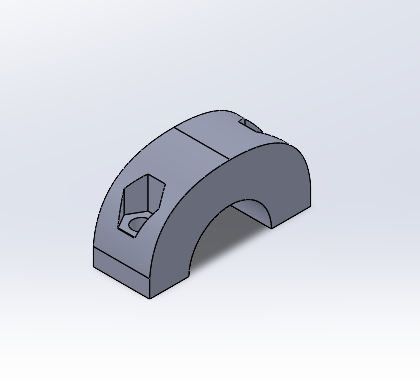
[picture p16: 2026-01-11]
images/Front_Bar_lock.png

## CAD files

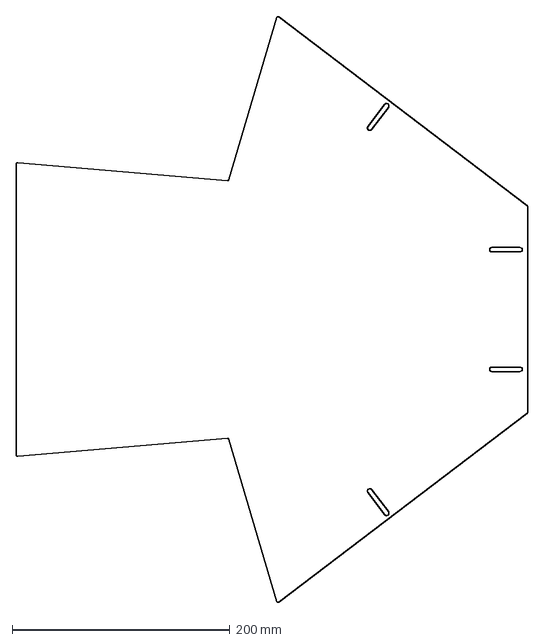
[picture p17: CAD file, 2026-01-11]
mechanical/Acrylic_Covers/EV_DXF/Single/main F.DXF
470.0 x 538.8 mm

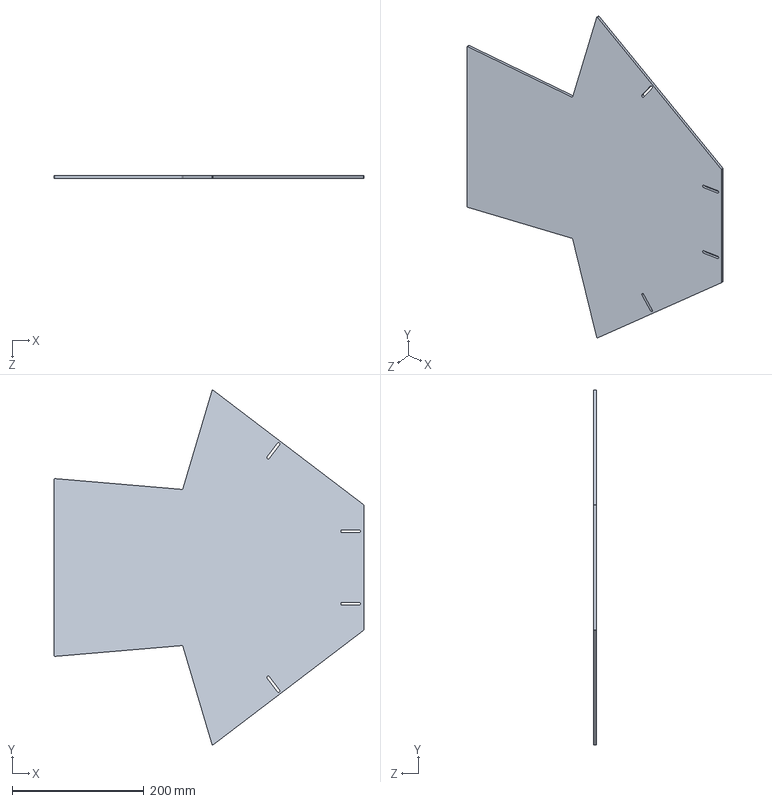
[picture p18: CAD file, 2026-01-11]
mechanical/Acrylic_Covers/Front Cover/main.SLDPRT
470.0 x 538.6 x 4.00 mm

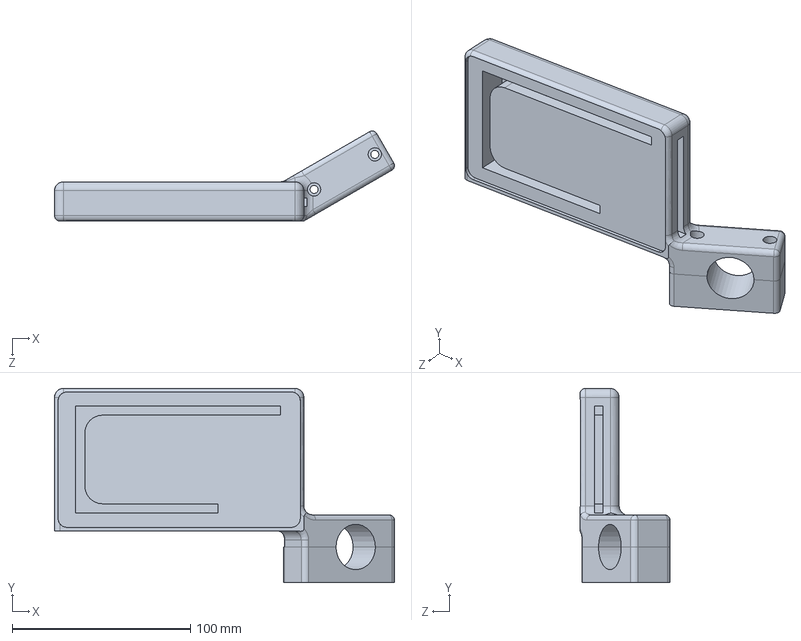
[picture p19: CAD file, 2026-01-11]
mechanical/3D_Printed_Parts/LED_Front_Right.SLDPRT
190.9 x 109.0 x 50.6 mm

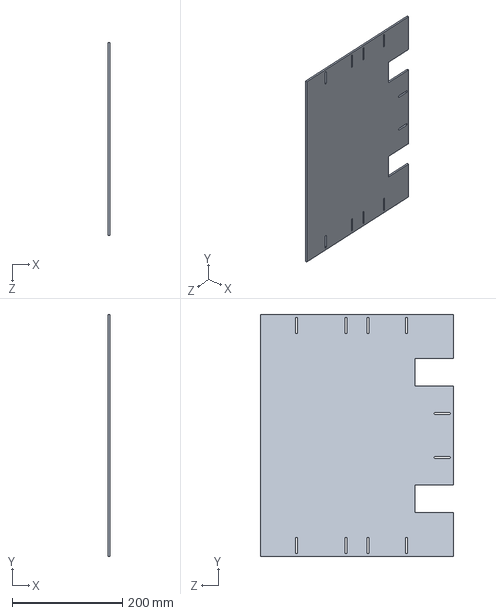
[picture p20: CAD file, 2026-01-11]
mechanical/Acrylic_Covers/Back Cover_lower/Mid.SLDPRT
4.00 x 440.0 x 350.0 mm

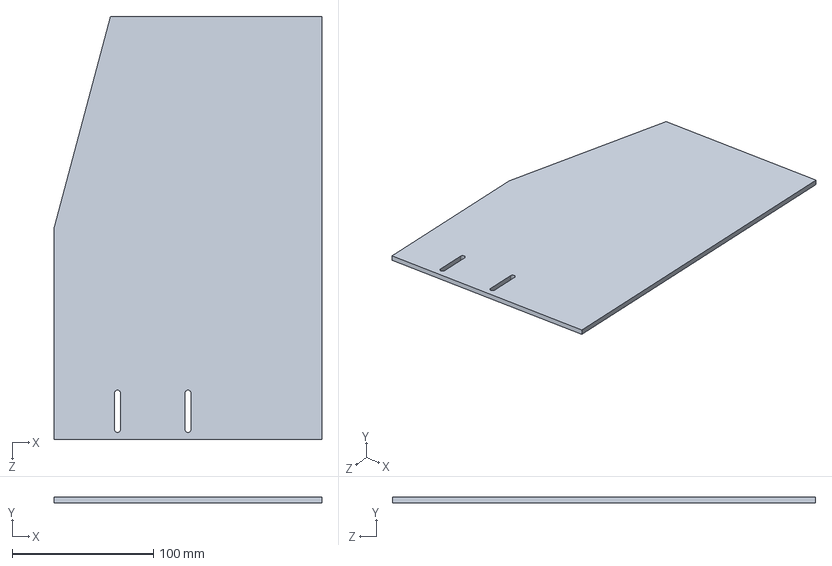
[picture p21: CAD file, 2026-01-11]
mechanical/Acrylic_Covers/Back Cover_Upper/side2.SLDPRT
190.0 x 4.00 x 300.0 mm

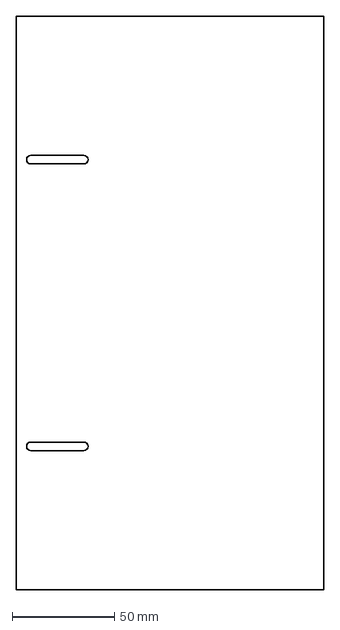
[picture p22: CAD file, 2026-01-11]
mechanical/Acrylic_Covers/EV_DXF/Double/side1 BU.DXF
150.0 x 280.0 mm

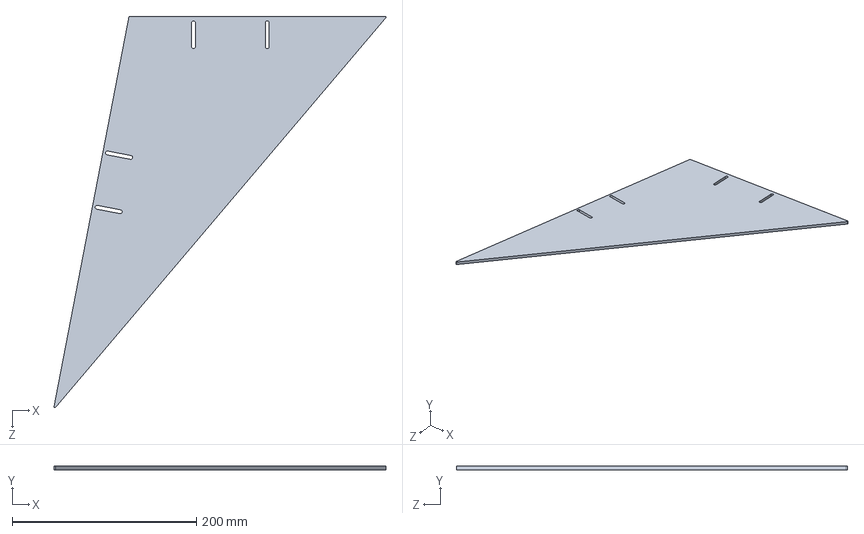
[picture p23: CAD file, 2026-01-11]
mechanical/Acrylic_Covers/Side Cover/Back.SLDPRT
360.2 x 4.00 x 424.6 mm

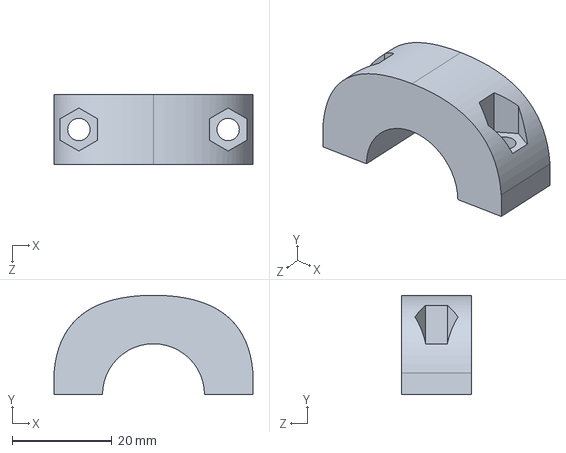
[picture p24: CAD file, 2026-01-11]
mechanical/3D_Printed_Parts/Front_Bar_lock.SLDPRT
40.0 x 20.0 x 14.0 mm

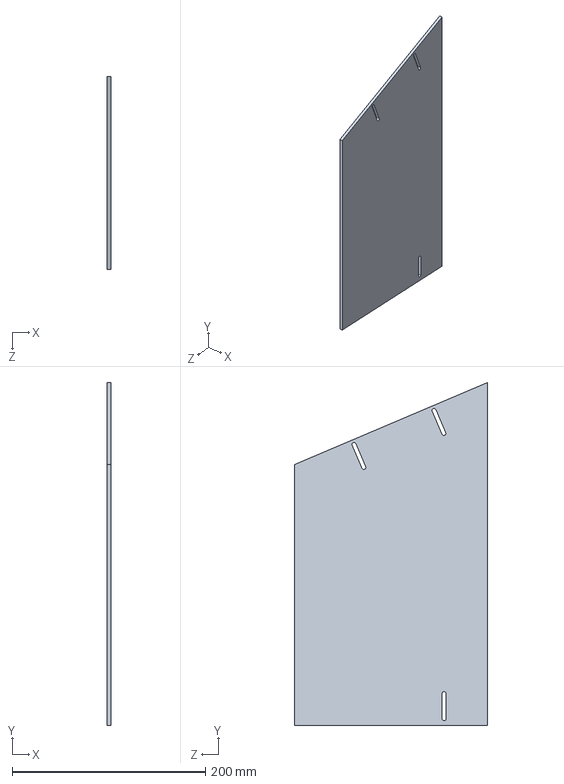
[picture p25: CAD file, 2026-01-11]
mechanical/Acrylic_Covers/Back Cover_lower/Side back.SLDPRT
4.00 x 355.0 x 200.0 mm

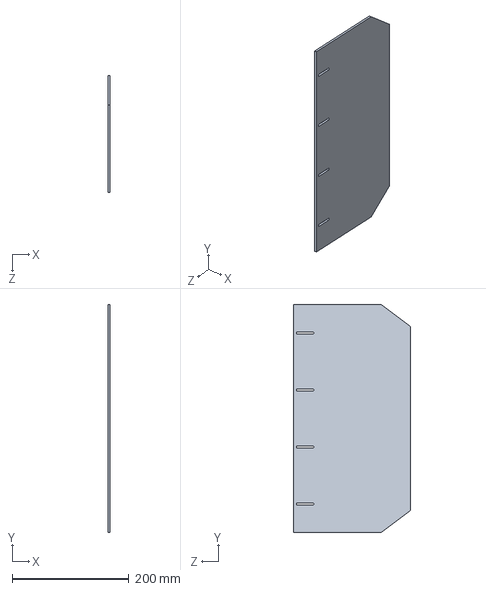
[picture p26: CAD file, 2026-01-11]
mechanical/Acrylic_Covers/Back Cover_Upper/mid.SLDPRT
4.00 x 390.0 x 200.0 mm

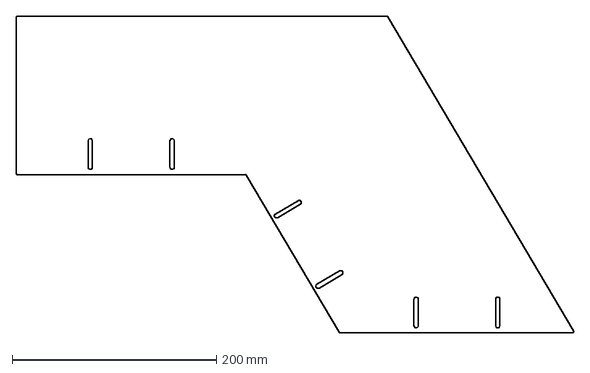
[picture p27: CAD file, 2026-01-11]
mechanical/Acrylic_Covers/EV_DXF/Double/Front Side.DXF
545.8 x 310.0 mm

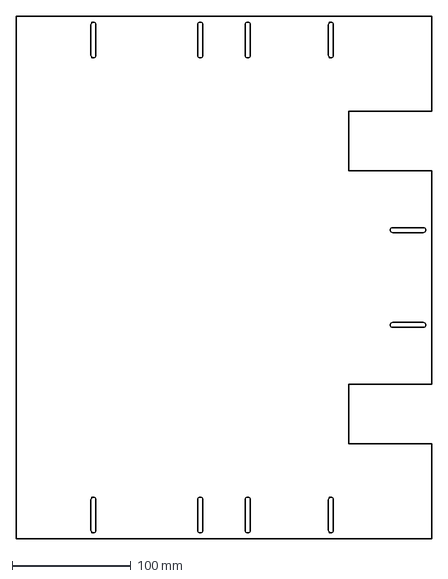
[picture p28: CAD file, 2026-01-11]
mechanical/Acrylic_Covers/EV_DXF/Single/Mid BL.DXF
350.0 x 440.0 mm

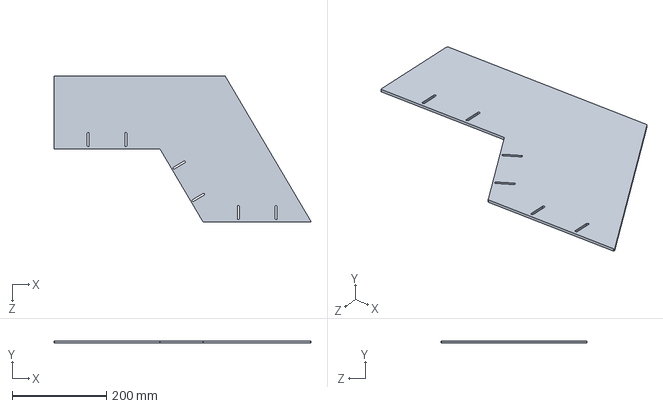
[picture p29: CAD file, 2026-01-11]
mechanical/Acrylic_Covers/Side Cover/Front.SLDPRT
545.8 x 4.00 x 310.0 mm

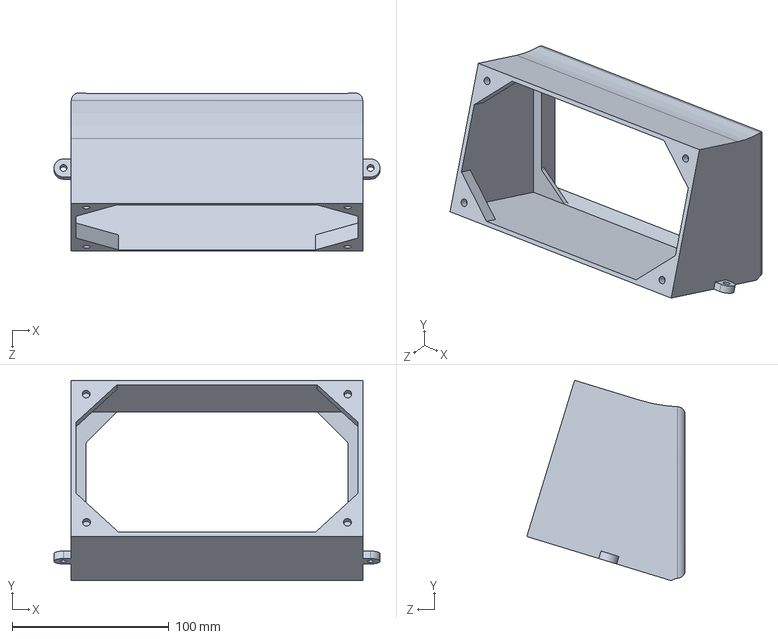
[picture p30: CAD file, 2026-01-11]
mechanical/3D_Printed_Parts/Control_Box_2.SLDPRT
208.0 x 127.9 x 101.1 mm

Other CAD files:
mechanical/Acrylic_Covers/Front Cover/Assem1.SLDASM
mechanical/Acrylic_Covers/Back Cover_Upper/side1.SLDPRT
mechanical/Acrylic_Covers/EV_DXF/Double/Mid Side.DXF
mechanical/Acrylic_Covers/EV_DXF/Single/mid BU.DXF
mechanical/3D_Printed_Parts/Control_Box_1.SLDPRT
mechanical/3D_Printed_Parts/Front_Bar.SLDPRT
mechanical/3D_Printed_Parts/Holder_1.SLDPRT
mechanical/3D_Printed_Parts/Holder_2.SLDPRT
mechanical/3D_Printed_Parts/Holder_3.SLDPRT
mechanical/3D_Printed_Parts/LED_Back.SLDPRT
mechanical/3D_Printed_Parts/LED_Front_Left.SLDPRT
mechanical/3D_Printed_Parts/Rear_Bar.SLDPRT
mechanical/Acrylic_Covers/Back Cover_Upper/mid.DXF
mechanical/Acrylic_Covers/Back Cover_Upper/side2.DXF
mechanical/Acrylic_Covers/Back Cover_lower/Side back.DXF
mechanical/Acrylic_Covers/EV_DXF/Double/Back Side.DXF
mechanical/Acrylic_Covers/EV_DXF/Double/Side BL.DXF
mechanical/Acrylic_Covers/EV_DXF/Double/Side F.DXF
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

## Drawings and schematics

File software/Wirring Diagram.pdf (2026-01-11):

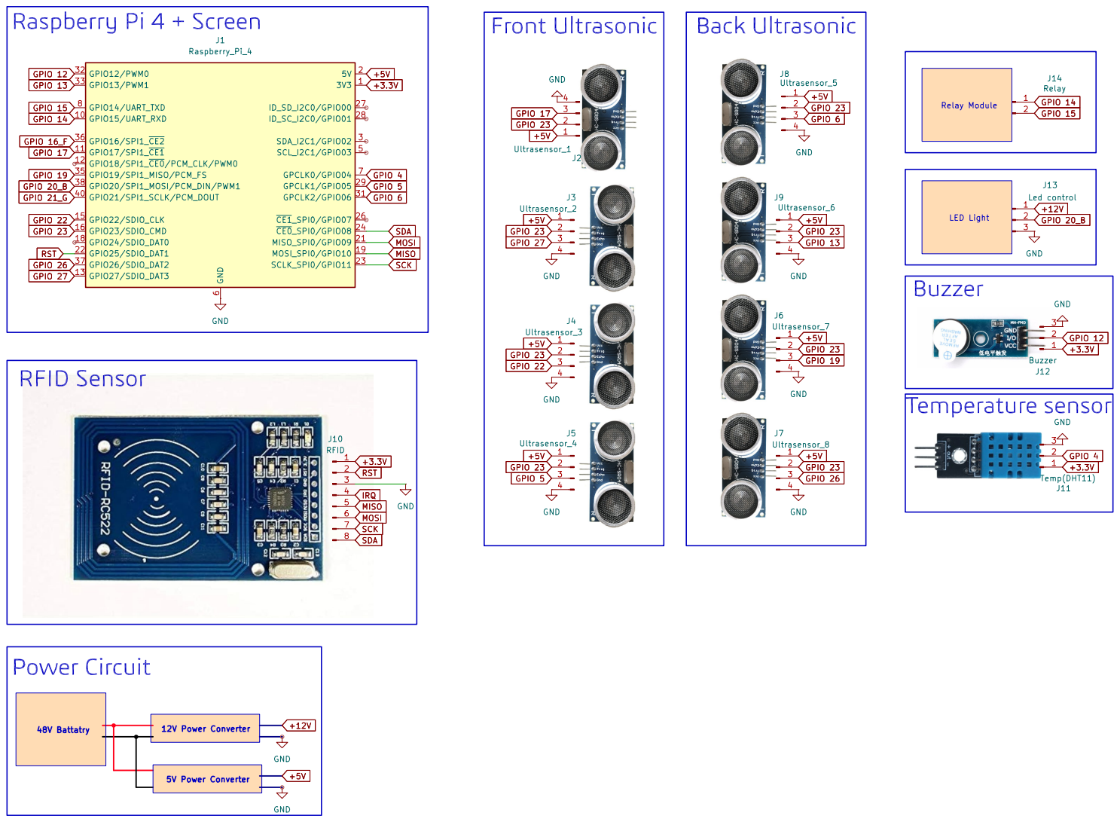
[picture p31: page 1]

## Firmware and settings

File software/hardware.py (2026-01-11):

import time
import threading
import random
import math

# --- HARDWARE DETECTION & IMPORTS ---
try:
    import RPi.GPIO as GPIO
    from gpiozero import DigitalInputDevice 
    from mfrc522 import SimpleMFRC522, MFRC522 
    # Added 'ws' to imports for strip type configuration
    from rpi_ws281x import PixelStrip, Color, ws
    import board
    import adafruit_dht
    IS_RASPBERRY_PI = True
except ImportError:
    print("⚠️ Hardware libraries not found. Running in MOCK (Simulation) Mode.")
    IS_RASPBERRY_PI = False
    
    # Mock classes
    class PixelStrip: 
        def __init__(self, num, *args): self.n = num
        def begin(self): pass
        def setPixelColor(self, *args): pass
        def show(self): pass
        def numPixels(self): return self.n
        def setBrightness(self, b): pass
    class Color: 
        def __init__(self, r,g,b): pass
    class DigitalInputDevice:
        def __init__(self, pin, pull_up=False): pass
    # Mock 'ws' class for PC
    class ws:
        WS2811_STRIP_RGB = 0

# ==========================================
#   USER CONFIGURATION
# ==========================================
# LED Counts (Edit these to match your actual strips)
LEDS_FRONT_COUNT    = 6
LEDS_INTERIOR_COUNT = 24
LEDS_BACK_COUNT     = 8
LED_TOTAL = LEDS_FRONT_COUNT + LEDS_INTERIOR_COUNT + LEDS_BACK_COUNT

# GPIO Pins (BCM Mode)
PIN_LED_DATA = 12  # PWM0 (Physical Pin 32) - Check your board label!
PIN_TRIG     = 23  # Shared Ultrasonic Trigger
PIN_BUZZER   = 13  # Active Buzzer
PIN_DHT      = 4   # Temp Sensor
PIN_RELAYS   = [14, 15] # Relay 1 (Motor), Relay 2 (Aux)
PIN_NFC_RST  = 19  # <--- UPDATED: NFC Reset Pin (Physical Pin 35)

# Ultrasonic Echo Pins (4 Front, 4 Rear)
# Swapped 13->24 and 19->16 previously
PINS_ECHO = [17, 27, 22, 5, 6, 24, 16, 26] 

# ==========================================
#   SUB-SYSTEM: LIGHTING
# ==========================================
class LightingSystem:
    def __init__(self):
        # UPDATED: Added 'strip_type=ws.WS2811_STRIP_RGB' to fix color swap
        self.strip = PixelStrip(LED_TOTAL, PIN_LED_DATA, 800000, 10, False, 255, 0, ws.WS2811_STRIP_RGB)
        if IS_RASPBERRY_PI:
            self.strip.begin()
        
        self.turn_signal_state = "OFF" 
        self.interior_color = (0, 0, 255)
        self.interior_mode = "SOLID"
        self.brake_active = False
        self.running = True
        self.anim_step = 0
        
        self.anim_thread = threading.Thread(target=self._animation_loop, daemon=True)
        self.anim_thread.start()

    def _animation_loop(self):
        blink_state = False
        while self.running:
            if IS_RASPBERRY_PI:
                self._render_front(blink_state)
                self._render_interior(blink_state)
                self._render_back(blink_state)
                self.strip.show()
            
            blink_state = not blink_state
            self.anim_step = (self.anim_step + 1) % 256
            time.sleep(0.4)

    def _render_front(self, blink):
        start = 0
        end = LEDS_FRONT_COUNT
        for i in range(start, end):
            if i < start + 1 and self.turn_signal_state in ["LEFT", "HAZARD"] and blink:
                self.strip.setPixelColor(i, Color(255, 150, 0))
            elif i >= end - 1 and self.turn_signal_state in ["RIGHT", "HAZARD"] and blink:
                self.strip.setPixelColor(i, Color(255, 150, 0))
            else:
                self.strip.setPixelColor(i, Color(255, 255, 255))

    def _render_interior(self, blink):
        start = LEDS_FRONT_COUNT
        end = start + LEDS_INTERIOR_COUNT
        r, g, b = self.interior_color

        if self.interior_mode == "SOLID":
            c = Color(r, g, b)
            for i in range(start, end): self.strip.setPixelColor(i, c)
        elif self.interior_mode == "BREATHE":
            factor = (math.sin(self.anim_step * 0.1) + 1) / 2
            c = Color(int(r * factor), int(g * factor), int(b * factor))
            for i in range(start, end): self.strip.setPixelColor(i, c)
        elif self.interior_mode == "RAINBOW":
            for i in range(start, end):
                pixel_hue = (i * 256 // (end-start)) + self.anim_step * 5
                c = self._wheel(pixel_hue & 255)
                self.strip.setPixelColor(i, c)

    def _render_back(self, blink):
        start = LEDS_FRONT_COUNT + LEDS_INTERIOR_COUNT
        end = LED_TOTAL
        base_color = Color(255, 0, 0) if self.brake_active else Color(255, 0, 0) 
        
        for i in range(start, end):
            if i < start + 2 and self.turn_signal_state in ["LEFT", "HAZARD"] and blink:
                self.strip.setPixelColor(i, Color(255, 150, 0))
            elif i >= end - 2 and self.turn_signal_state in ["RIGHT", "HAZARD"] and blink:
                self.strip.setPixelColor(i, Color(255, 150, 0))
            else:
                self.strip.setPixelColor(i, base_color)

    def _wheel(self, pos):
        if pos < 85: return Color(pos * 3, 255 - pos * 3, 0)
        elif pos < 170: pos -= 85; return Color(255 - pos * 3, 0, pos * 3)
        else: pos -= 170; return Color(0, pos * 3, 255 - pos * 3)

    def set_turn_signal(self, mode): self.turn_signal_state = mode
    def set_brakes(self, is_active): self.brake_active = is_active
    def set_interior_rgb(self, r, g, b): self.interior_color = (r, g, b)
    def set_interior_mode(self, mode): self.interior_mode = mode

# ==========================================
#   MAIN HARDWARE CONTROLLER
# ==========================================
class CarHardware:
    def __init__(self):
        self.distances = [0.0] * 8
        self.nfc_id = None
        self.nfc_text = None
        self.temp_data = {"t": 0.0, "h": 0.0}
        self.running = True
        self.echo_devices = []
        self._echo_start_times = [0.0] * 8
        
        self.lights = LightingSystem()
        
        if IS_RASPBERRY_PI:
            self._init_gpio()
            self._start_threads()
        else:
            self._init_mock()

    def _init_gpio(self):
        # 1. Output Pins (Use RPi.GPIO for outputs)
        GPIO.setmode(GPIO.BCM)
        GPIO.setwarnings(False)
        GPIO.setup(PIN_TRIG, GPIO.OUT)
        GPIO.setup(PIN_BUZZER, GPIO.OUT)
        # Relays Active Low: Start HIGH (OFF)
        GPIO.setup(PIN_RELAYS, GPIO.OUT, initial=GPIO.HIGH)

        # 2. Input Pins (Use gpiozero for robust reading on Bookworm)
        # We manually attach the callbacks using gpiozero's backend
        for idx, pin in enumerate(PINS_ECHO):
            # pull_up=False is critical because you have voltage dividers!
            sensor = DigitalInputDevice(pin, pull_up=False)
            
            # Using lambdas to capture the index 'i' correctly
            sensor.when_activated = lambda i=idx: self._on_echo_rise(i)
            sensor.when_deactivated = lambda i=idx: self._on_echo_fall(i)
            
            self.echo_devices.append(sensor)

        self.dht_device = adafruit_dht.DHT11(board.D4, use_pulseio=False)
        
        # 4. NFC
        try:
            self.nfc_core = MFRC522(pin_rst=PIN_NFC_RST)
            version = self.nfc_core.Read_MFRC522(MFRC522.VersionReg)
            
            if version in [0x91, 0x92]: 
                self.nfc_reader = SimpleMFRC522()
                self.nfc_reader.READER = self.nfc_core
                print(f"NFC Initialized (Ver: {hex(version)})")
            else:
                print(f"NFC Check Failed: {hex(version)}")
                self.nfc_reader = None
                
        except Exception as e:
            print(f"Error initializing NFC: {e}")
            self.nfc_reader = None

    def _start_threads(self):
        threading.Thread(target=self._nfc_loop, daemon=True).start()
        threading.Thread(target=self._temp_loop, daemon=True).start()

    # --- UPDATED SENSOR LOGIC (Using gpiozero callbacks) ---
    def _on_echo_rise(self, idx):
        """Called when Echo goes HIGH"""
        self._echo_start_times[idx] = time.time()

    def _on_echo_fall(self, idx):
        """Called when Echo goes LOW"""
        if self._echo_start_times[idx] > 0:
            duration = time.time() - self._echo_start_times[idx]
            dist = (duration * 34300) / 2
            # Filter between 20cm and 400cm
            if 20 < dist < 400:
                self.distances[idx] = round(dist, 1)

    def trigger_sensors(self):
        if IS_RASPBERRY_PI:
            GPIO.output(PIN_TRIG, True)
            time.sleep(0.00001)
            GPIO.output(PIN_TRIG, False)
        else:
            for i in range(8): self.distances[i] = max(0, min(300, self.distances[i] + random.uniform(-2, 2)))

    def set_relay(self, index, state):
        if IS_RASPBERRY_PI:
            if 0 <= index < len(PIN_RELAYS):
                val = GPIO.LOW if state else GPIO.HIGH
                GPIO.output(PIN_RELAYS[index], val)
        else:
            print(f"MOCK: Relay {index} -> {state}")

    def set_light(self, name, state):
        pass 

    def beep(self, duration=0.1):
        """Blocking beep"""
        if IS_RASPBERRY_PI:
            GPIO.output(PIN_BUZZER, True)
            time.sleep(duration)
            GPIO.output(PIN_BUZZER, False)
        else: pass
    
    def set_buzzer(self, state):
        """Non-blocking buzzer"""
        if IS_RASPBERRY_PI:
            GPIO.output(PIN_BUZZER, GPIO.HIGH if state else GPIO.LOW)
        else:
            if state: print("MOCK: Buzzer ON")

    def _nfc_loop(self):
        while self.running and self.nfc_reader:
            try:
                id, text = self.nfc_reader.read()
                self.nfc_id = id; self.nfc_text = text
                self.beep(0.1)
                time.sleep(2)
            except: time.sleep(0.5)

    def _temp_loop(self):
        while self.running:
            if IS_RASPBERRY_PI:
                try:
                    t = self.dht_device.temperature; h = self.dht_device.humidity
                    if t: self.temp_data["t"] = t
                    if h: self.temp_data["h"] = h
                except: pass
            time.sleep(2.0)

    def cleanup(self):
        self.running = False
        self.lights.running = False
        if IS_RASPBERRY_PI:
            if hasattr(self, 'dht_device'): self.dht_device.exit()
            GPIO.cleanup()
            for i in range(self.lights.strip.numPixels()):
                self.lights.strip.setPixelColor(i, Color(0,0,0))
            self.lights.strip.show()

    def _init_mock(self):
        self.distances = [120.0] * 8
        self.temp_data = {"t": 24.5, "h": 50}
        threading.Timer(5.0, lambda: setattr(self, 'nfc_id', 999999)).start()

# --- STANDALONE TEST MODE ---
if __name__ == "__main__":
    print("--- STARTING HARDWARE STANDALONE MODE ---")
    print("Initializing components (LEDs, NFC, Sensors, Relays)...")
    try:
        car = CarHardware()
        print("Hardware initialized successfully.")
        print("Running background threads... Press CTRL+C to exit.")
        while True:
            car.trigger_sensors()
            time.sleep(0.5)
            print(f"Distances: {car.distances}")
            
    except KeyboardInterrupt:
        print("\nStopping...")
        car.cleanup()

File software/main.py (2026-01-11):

import sys
import os
import math
from PyQt5.QtWidgets import (QApplication, QMainWindow, QWidget, QGridLayout, 
                             QVBoxLayout, QHBoxLayout, QLabel, QPushButton, QFrame, 
                             QStackedWidget, QSlider, QMessageBox, QListWidget, QHeaderView, 
                             QTableWidget, QTableWidgetItem, QInputDialog, QLineEdit, QSizePolicy)
from PyQt5.QtCore import QTimer, Qt, QDateTime, QPoint
from PyQt5.QtGui import QFont, QColor, QPalette, QPainter, QPen, QBrush, QPolygon, QPainterPath, QLinearGradient

# Import our verified Hardware Class
from hardware import CarHardware

# --- GLOBAL PATH CONFIGURATION ---
# This ensures files are found even when running on boot
BASE_DIR = os.path.dirname(os.path.abspath(__file__))
KEY_FILE = os.path.join(BASE_DIR, "authorized_keys.txt")

# --- THEME CONFIGURATION (LIGHT MODE) ---
THEME = {
    "bg_dark": "#ffffff",        # White Background
    "bg_panel": "rgba(240, 240, 240, 220)", # Semi-transparent white panels
    "accent_cyan": "#0088cc",    # Darker Cyan for white background contrast
    "accent_red": "#dd3333",
    "accent_green": "#00aa44",
    "accent_amber": "#ffaa00",
    "text_main": "#111111",      # Dark Text
    "text_dim": "#555555",
    "menu_bg": "#e0e0e0",
    "menu_sel": "#cccccc"
}

class ParkingVisualizer(QWidget):
    def __init__(self):
        super().__init__()
        self.distances = [0.0] * 8
        self.setMinimumSize(300, 400) 
        self.setSizePolicy(QSizePolicy.Expanding, QSizePolicy.Expanding)

    def update_sensor_data(self, distances):
        self.distances = distances
        self.update() 

    def paintEvent(self, event):
        painter = QPainter(self)
        painter.setRenderHint(QPainter.Antialiasing)
        
        w = self.width()
        h = self.height()
        
        # --- 1. DRAW RADAR GRID BACKGROUND ---
        self.draw_grid(painter, w, h)

        # --- 2. SCALING LOGIC ---
        # Adjusted for 7-inch screen proportions
        scene_w = 320
        scene_h = 520
        scale = min(w / scene_w, h / scene_h) * 0.95 # Maximize fill
        
        painter.translate(w / 2, h / 2)
        painter.scale(scale, scale)
        
        cx = 0
        cy = 0
        
        # --- 3. OFF-ROAD BUGGY DIMENSIONS ---
        body_w = 120  
        body_h = 250 
        
        # Suspension
        painter.setPen(QPen(QColor(160, 160, 160), 10)) 
        painter.drawLine(cx - 25, cy - 70, cx - 100, cy - 95) 
        painter.drawLine(cx + 25, cy - 70, cx + 100, cy - 95) 
        painter.drawLine(cx - 25, cy + 70, cx - 100, cy + 90) 
        painter.drawLine(cx + 25, cy + 70, cx + 100, cy + 90) 

        # Tires (Detailed Tread)
        painter.setBrush(QBrush(QColor(20, 20, 20))) 
        painter.setPen(QPen(QColor(5, 5, 5), 2))
        wheel_w = 48 
        wheel_h = 85 
        
        self.draw_tire(painter, cx - 100, cy - 95, -8, wheel_w, wheel_h) # FL
        self.draw_tire(painter, cx + 100, cy - 95, 8, wheel_w, wheel_h)  # FR
        
        # Fixed Rear Wheel Symmetry
        self.draw_tire(painter, cx - 100, cy + 80, 0, wheel_w, wheel_h)  # RL
        self.draw_tire(painter, cx + 100, cy + 80, 0, wheel_w, wheel_h)  # RR

        # Body Gradient (BLACK)
        grad = QLinearGradient(0, -body_h//2, 0, body_h//2)
        grad.setColorAt(0, QColor(60, 60, 60))    # Dark Grey
        grad.setColorAt(1, QColor(10, 10, 10))    # Black
        painter.setBrush(QBrush(grad))
        painter.setPen(QPen(QColor(0, 0, 0), 4))
        
        # Tub Shape
        poly = QPolygon()
        poly.append(QPoint(cx - 40, cy - body_h//2))      
        poly.append(QPoint(cx + 40, cy - body_h//2))      
        poly.append(QPoint(cx + body_w//2, cy - 45))      
        poly.append(QPoint(cx + body_w//2, cy + 70))      
        poly.append(QPoint(cx + 40, cy + body_h//2))      
        poly.append(QPoint(cx - 40, cy + body_h//2))      
        poly.append(QPoint(cx - body_w//2, cy + 70))      
        poly.append(QPoint(cx - body_w//2, cy - 45))      
        painter.drawPolygon(poly)

        # Roll Cage (Silver/Chrome)
        painter.setPen(QPen(QColor(200, 200, 200), 6)) 
        painter.setBrush(Qt.NoBrush)
        painter.drawRect(cx - 45, cy - 55, 90, 125)
        painter.drawLine(cx - 45, cy - 55, cx + 45, cy + 70)
        painter.drawLine(cx + 45, cy - 55, cx - 45, cy + 70)

        # Spare Tire
        painter.setBrush(QBrush(QColor(20, 20, 20)))
        painter.setPen(QPen(QColor(0, 0, 0), 3))
        painter.drawEllipse(cx - 35, cy + body_h//2 - 50, 70, 70)
        painter.setBrush(QBrush(QColor(150, 150, 150)))
        painter.drawEllipse(cx - 12, cy + body_h//2 - 27, 24, 24)

        # Headlights
        painter.setBrush(QBrush(QColor(240, 240, 255))) # Xenon White
        painter.setPen(QPen(QColor(150, 150, 150), 2))
        painter.drawEllipse(cx - 50, cy - body_h//2 + 12, 22, 22)
        painter.drawEllipse(cx + 28, cy - body_h//2 + 12, 22, 22)

        # --- SENSORS ---
        # Front
        self.draw_radar_arc(painter, cx, cy - body_h//2, -55, self.distances[0]) 
        self.draw_radar_arc(painter, cx, cy - body_h//2, -20, self.distances[1]) 
        self.draw_radar_arc(painter, cx, cy - body_h//2,  20, self.distances[2]) 
        self.draw_radar_arc(painter, cx, cy - body_h//2,  55, self.distances[3]) 
        # Rear
        self.draw_radar_arc(painter, cx, cy + body_h//2, 235, self.distances[4]) 
        self.draw_radar_arc(painter, cx, cy + body_h//2, 200, self.distances[5]) 
        self.draw_radar_arc(painter, cx, cy + body_h//2, 160, self.distances[6]) 
        self.draw_radar_arc(painter, cx, cy + body_h//2, 125, self.distances[7]) 

    def draw_grid(self, painter, w, h):
        pen = QPen(QColor(0, 0, 0, 30)) # Stronger grid for white bg
        pen.setWidth(1)
        painter.setPen(pen)
        step = 50
        for x in range(0, w, step): painter.drawLine(x, 0, x, h)
        for y in range(0, h, step): painter.drawLine(0, y, w, y)
        painter.setPen(QPen(QColor(0, 0, 0, 20), 2))
        center = QPoint(w//2, h//2)
        painter.drawEllipse(center, 100, 100)
        painter.drawEllipse(center, 200, 200)
        painter.drawEllipse(center, 300, 300)

    def draw_tire(self, painter, x, y, angle, w, h):
        painter.save()
        painter.translate(x, y)
        painter.rotate(angle)
        painter.drawRoundedRect(-w//2, -h//2, w, h, 8, 8)
        painter.setPen(QPen(QColor(50, 50, 50), 2))
        painter.drawLine(-w//2 + 5, -h//4, w//2 - 5, -h//4)
        painter.drawLine(-w//2 + 5, 0, w//2 - 5, 0)
        painter.drawLine(-w//2 + 5, h//4, w//2 - 5, h//4)
        painter.restore()
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

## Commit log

2026-01-11 Init Mechanical file
    [Assem1.SLDASM, Back Side.DXF, Back.DXF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]
2026-01-11 Add Mechanical readme file
    [Assem1.SLDASM, Back Side.DXF, Back.DXF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]
2026-01-11 adding images
    [EV_CU.kicad_pcb, EV_CU.kicad_sch]
2026-11-03 refactor(tests): organize test and calibration scripts into testing/ directory
2026-11-03 style(ui): enlarge ENTER PIN and SCAN CARD controls and position in upper-right with upward arrow
2026-11-03 style(ui): enlarge dashboard buttons, icons, and telemetry for 1080p touchscreen
2026-11-03 style(ui): vertically expand time, date, and temp to meet light and reverse buttons
2026-11-03 style(ui): enlarge typography, rows, and buttons in settings diagnostics and access config
2026-11-04 feat(jetson): add live Jetson status/temp button and embedded 192.168.10.112:3000 Explorer screen with power-saving fixes
2026-11-04 perf(jetson): optimize poll latency and rate-limit SSH thermal checks
2026-11-04 feat(sensors): add median filtering, EMA smoothing, and trigger rate limiting to eliminate ultrasonic noise
2026-11-04 feat(radar): limit ultrasonic detection to 60cm max and silence buzzer when out of range
2026-11-04 fix(sensors): synchronous ultrasonic edge capture with consensus cluster filter
2026-11-04 fix(sensors): account for 12.2ms hardware echo rise delay in background capture loop
2026-11-04 fix(jetson): inject roundRect polyfill and GPU acceleration for 2D/3D mapping and satellite Leaflet map
